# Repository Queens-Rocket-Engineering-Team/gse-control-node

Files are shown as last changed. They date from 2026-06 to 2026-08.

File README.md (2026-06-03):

# GSE Control Node

The GSE control node is the control PCB for GSE systems to integrate with launch control. This includes actuator control, fan control, and a load cell reading. This control node is used for control of the GSE equipment on the launch tower.

## System Architecture

Control nodes use an ESP32S3-WROOM-1U microcontroller for systems control. This ESP32S3 communicates with an external control
server to for remote control and data streaming over 2.4GHz WiFi. All commands are sent from the external server, as
control nodes does not autonomously control any systems.

A communications diagram for the GSE control node can be seen below.

```mermaid
---
title: Communications Flow
---
flowchart LR

    ADC(ADS112C04<br>ADCs) <==I2C==> ESP(ESP32 MCU)

    subgraph Controls
        AV(Actuators)
    end

    subgraph Sensors
        LC(Load Cell)
    end

    LC --> ADC

    ESP --> AV

    ESP <-. WiFI .-> WIFI(External Server)
```

## Power Architecture

The GSE control node operates from a 24VDC power supply. The 24V rail is first stepped down to 5.17V with a switching converter and then dropped to 5V and 3.3V with LDOs. The 5V rail supplies analog systems, and the 3.3V rail supplies digital systems. Using LDOs on the switching output allows for low-noise power for analog measurements. There is also a switching converter to step the 24V rail down to 12V, to power fans.

```mermaid
---
title: Power Distribution
---
flowchart LR

    subgraph Actuators
        AV(Actuators)
    end
    24VIN --> AV

    subgraph Voltage Regulation
        BUCK_12([12V Buck])
        BUCK_5.17([5.17V Buck])
        BUCK_5.17 --> 5V([5V LDO])
        BUCK_5.17 --> 3V3([3.3V LDO])
    end

    24VIN --> BUCK_12
    24VIN --> BUCK_5.17

    subgraph Fans
        FANS(Fans)
    end

    subgraph Sensors
        LC(Load Cell)
    end

    BUCK_12 ---> FANS
    5V --> ADC(ADS112C04<br>ADCs)
    3V3 --> ESP(ESP32 MCU)
    3V3 --> ADC
    5V --> LC
```

## Required Software

This project was created using KiCad v10.0. If manufacturing with JLCPCB, install the Fabrication Toolkit KiCad plugin for JLCPCB.

## Recommended Manufacturing Options

If ordering from JLCPCB, use the JLC04161H-3313 stackup option. For JLC PCBA, the standard PCBA option is required due
to the ESP32S3-WROOM-1U being unavailable as a part in the economic PCBA assembly.

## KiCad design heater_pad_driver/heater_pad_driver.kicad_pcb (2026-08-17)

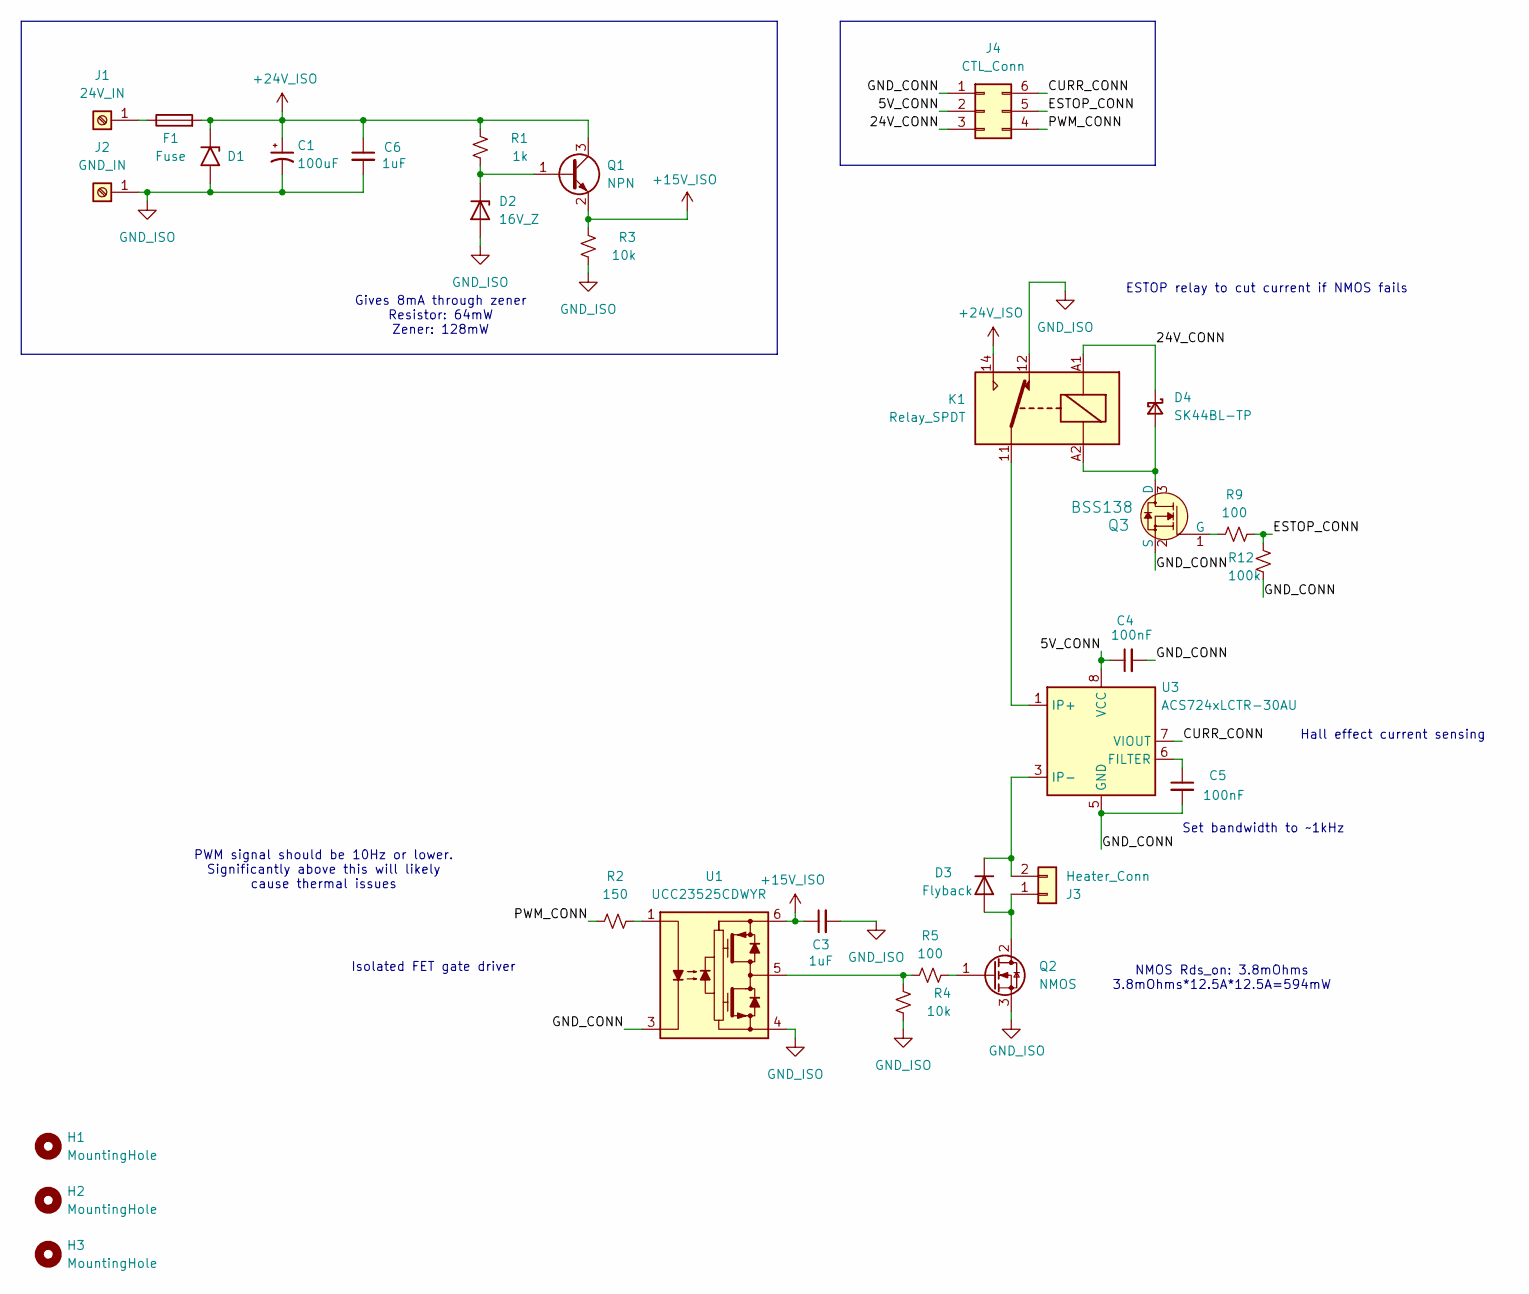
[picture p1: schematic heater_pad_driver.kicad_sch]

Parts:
C1: 100uF; CP_Radial_D8.0mm_P5.00mm; MPN EEU-FR1H101B
C3, C6: 1uF; C_0805_2012Metric_Pad1.18x1.45mm_HandSolder
C4, C5: 100nF; C_0805_2012Metric_Pad1.18x1.45mm_HandSolder
D1: SMCJ26A-13-F; D_SMC
D2: 16V_Z; D_SOD-123; MPN MMSZ5246BT1G
D3: Flyback; TO-220F-2_Vertical; MPN SDURK20Q60
D4: SK44BL-TP; D_SMB_Handsoldering; MPN SK44BL-TP
F1: Fuse; Fuseholder_Blade_Mini_Keystone_3568
H1, H2, H3: MountingHole; MountingHole_3.2mm_M3
J1: 24V_IN; AMT0440007DB0000G; MPN AMT0440007DB0000G
J2: GND_IN; AMT0440007DB0000G; MPN AMT0440007DB0000G
J3: Heater_Conn; AMASS_XT60PW-M_1x02_P7.20mm_Horizontal
J4: CTL_Conn; Molex_Micro-Fit_3.0_43045-0612_2x03_P3.00mm_Vertical
K1: Relay_SPDT; AZ576-1C
Q1: NPN; SOT-23_Handsoldering; MPN MMBTA06LT1G
Q2: NMOS; TO-252-2; MPN DMTH6004SK3Q-13
Q3: BSS138; SOT-23; MPN BSS138
R1: 1k; R_0805_2012Metric_Pad1.20x1.40mm_HandSolder
R2: 150; R_0805_2012Metric_Pad1.20x1.40mm_HandSolder
R3, R4: 10k; R_0805_2012Metric_Pad1.20x1.40mm_HandSolder
R5, R9: 100; R_0805_2012Metric_Pad1.20x1.40mm_HandSolder
R12: 100k; R_0805_2012Metric_Pad1.20x1.40mm_HandSolder
U1: UCC23525CDWYR; SSO-6_6.8x4.6mm_P1.27mm_Clearance8mm
U3: ACS724xLCTR-30AU; SOIC-8_3.9x4.9mm_P1.27mm; MPN ACS724LLCTR-30AU-T

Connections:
+15V_ISO: C3.1, Q1.2 (E), R3.2, U1.6 (VCC)
+24V_ISO: C1.1, C6.1, D1.1 (A1), F1.2, K1.14, Q1.3 (C), R1.2
/5V_CONN: C4.1, J4.2, U3.8 (VCC)
/24V_CONN: D4.1 (K), J4.3, K1.A1
/CURR_CONN: J4.6, U3.7 (VIOUT)
/ESTOP_CONN: J4.5, R9.2, R12.1
/GND_CONN: C4.2, C5.2, J4.1, Q3.2 (S), R12.2, U1.3 (C), U3.5 (GND)
/PWM_CONN: J4.4, R2.2
GND_ISO: C1.2, C3.2, C6.2, D1.2 (A2), D2.2 (A), J2.1 (Pin_1_1), K1.12, Q2.3 (S), R3.1, R4.1, U1.4 (VEE)
unnamed: D2.1 (K), Q1.1 (B), R1.1
unnamed: D3.2 (A), J3.1, Q2.2 (D)
unnamed: D3.1 (K), J3.2, U3.3 (IP-), U3.4 (IP-)
unnamed: D4.2 (A), K1.A2, Q3.3 (D)
unnamed: F1.1, J1.1 (Pin_1_1)
unnamed: K1.11, U3.1 (IP+), U3.2 (IP+)
unnamed: Q2.1 (G), R5.2
unnamed: Q3.1 (G), R9.1
unnamed: R2.1, U1.1 (A)
unnamed: R4.2, R5.1, U1.5 (VO)
unnamed: C5.1, U3.6 (FILTER)

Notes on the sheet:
Gives 8mA through zener Resistor: 64mW Zener: 128mW
Set bandwidth to ~1kHz
ESTOP relay to cut current if NMOS fails
Isolated FET gate driver
Hall effect current sensing
PWM signal should be 10Hz or lower. Significantly above this will likely cause thermal issues
NMOS Rds_on: 3.8mOhms 3.8mOhms*12.5A*12.5A=594mW

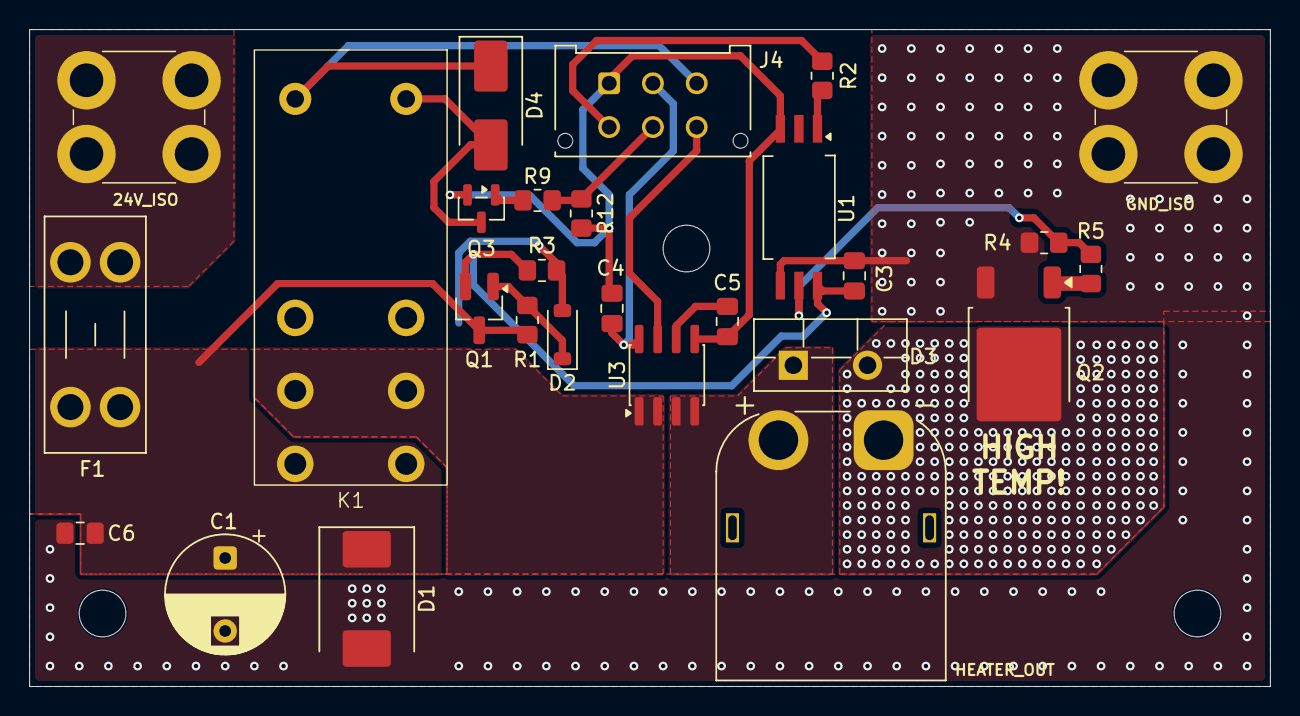
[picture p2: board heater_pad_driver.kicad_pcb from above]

Board: 2 copper layers, 85.0 x 45.0 mm, 30 parts (0 on the bottom side), 20 nets.

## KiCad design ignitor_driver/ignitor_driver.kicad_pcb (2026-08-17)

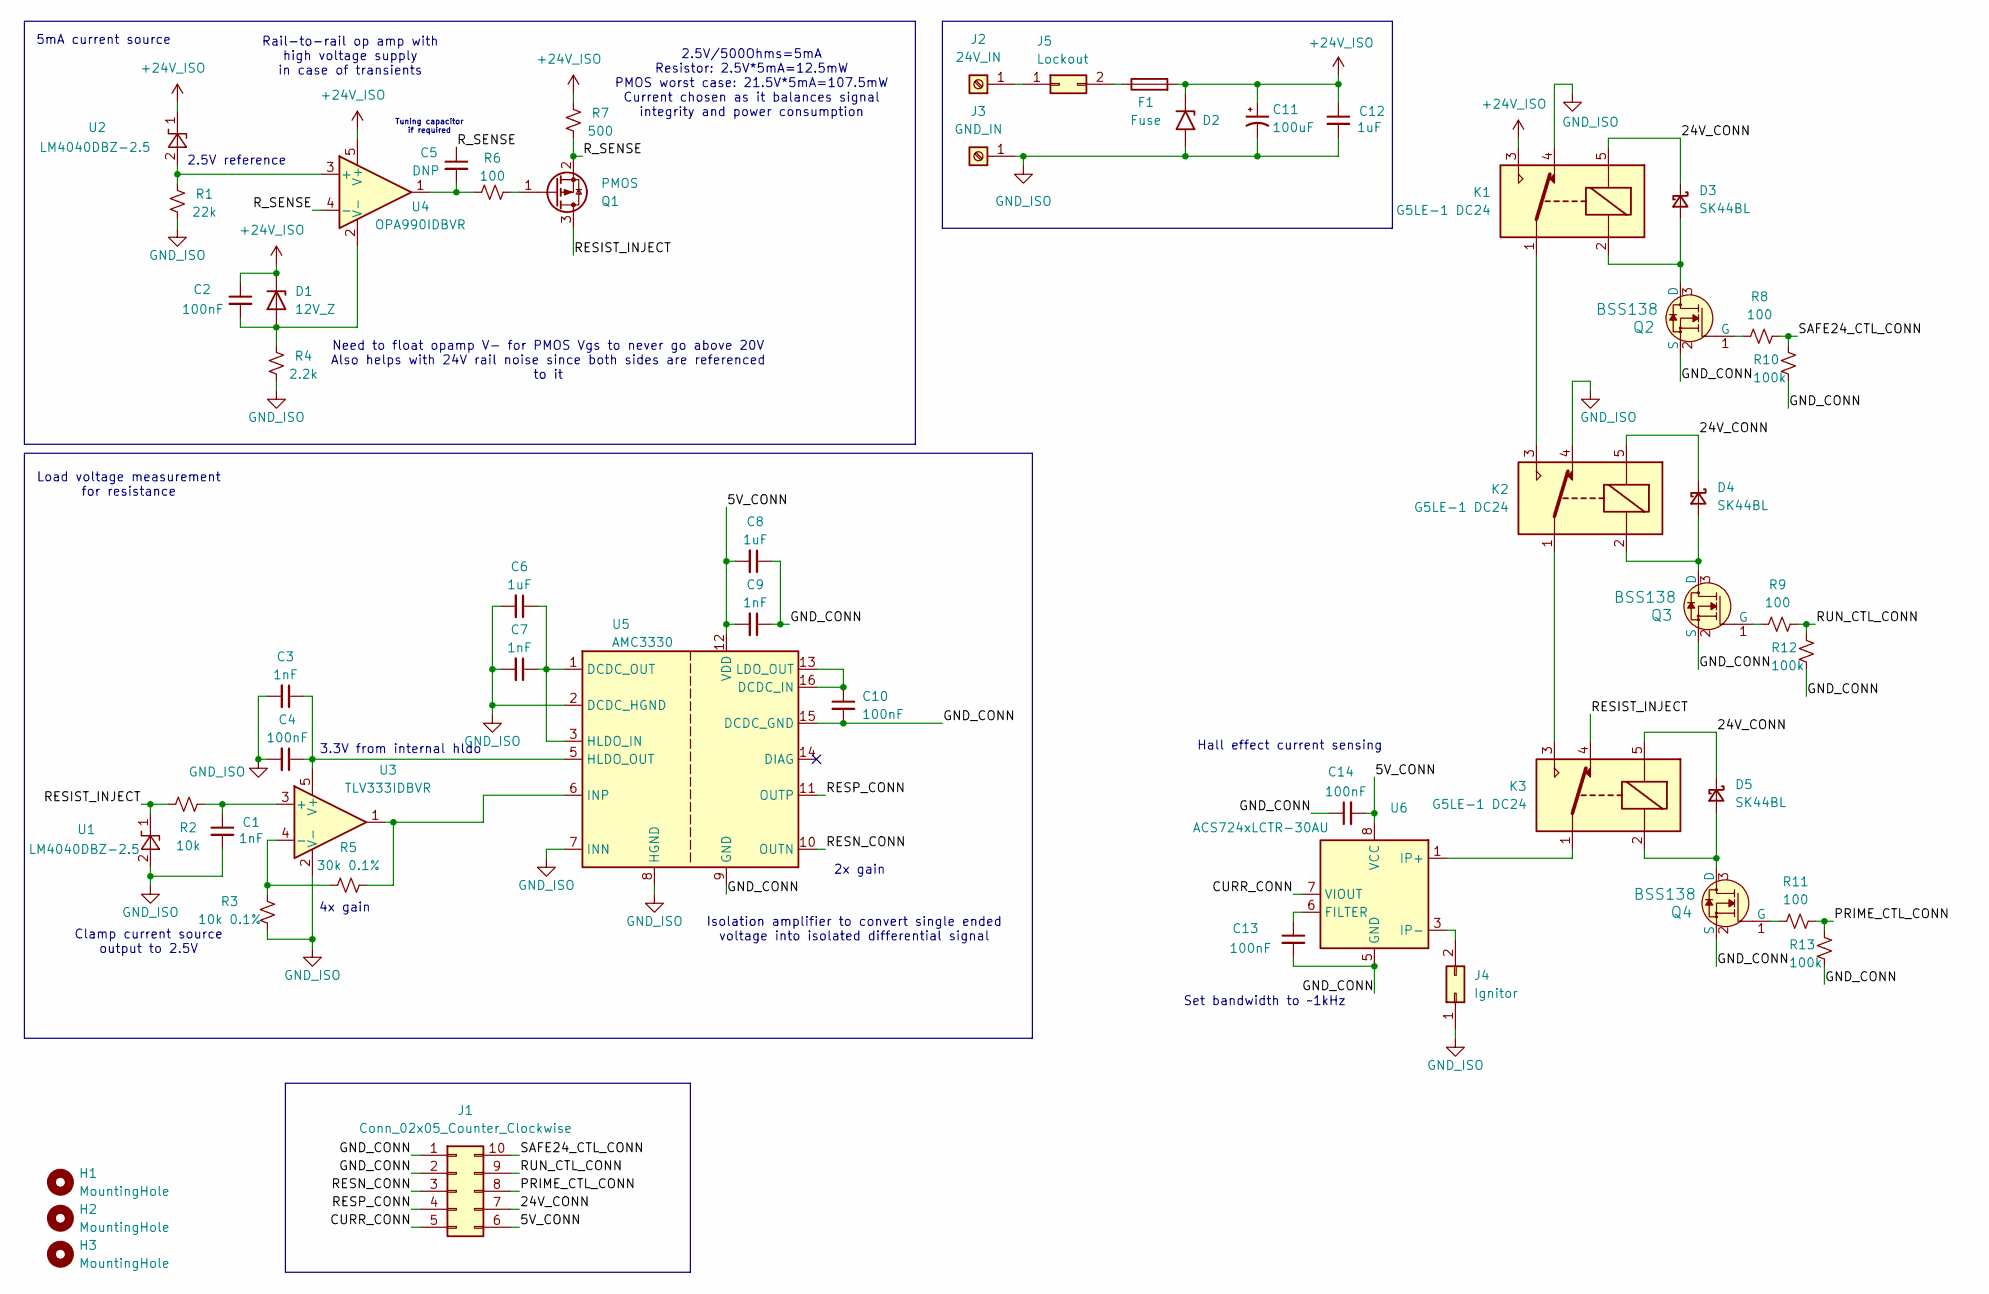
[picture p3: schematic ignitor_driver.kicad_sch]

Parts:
C1, C3, C7, C9: 1nF; C_0805_2012Metric_Pad1.18x1.45mm_HandSolder
C2, C4, C10, C13, C14: 100nF; C_0805_2012Metric_Pad1.18x1.45mm_HandSolder
C5: DNP; C_0805_2012Metric_Pad1.18x1.45mm_HandSolder
C6, C8, C12: 1uF; C_0805_2012Metric_Pad1.18x1.45mm_HandSolder
C11: 100uF; CP_Radial_D8.0mm_P5.00mm; MPN EEU-FR1H101B
D1: 12V_Z; D_SOD-123; MPN BZT52C12-13-F
D2: SMCJ26A-13-F; D_SMC; MPN SMCJ26A
D3, D4, D5: SK44BL; D_SMB_Handsoldering; MPN SK44BL-TP
F1: Fuse; Fuseholder_Blade_Mini_Keystone_3568
H1, H2, H3: MountingHole; MountingHole_3.2mm_M3
J1: Conn_02x05_Counter_Clockwise; Molex_Micro-Fit_3.0_43045-1012_2x05_P3.00mm_Vertical
J2: 24V_IN; AMT0440007DB0000G; MPN AMT0440007DB0000G
J3: GND_IN; AMT0440007DB0000G; MPN AMT0440007DB0000G
J4: Ignitor; Molex_Mini-Fit_Jr_5566-02A_2x01_P4.20mm_Vertical
J5: Lockout; Molex_Mini-Fit_Jr_5566-02A_2x01_P4.20mm_Vertical
K1, K2, K3: G5LE-1 DC24; Relay_SPDT_Omron-G5LE-1
Q1: PMOS; SOT-23; MPN BSS83PH6327XTSA1
Q2, Q3, Q4: BSS138; SOT-23; MPN BSS138
R1: 22k; R_0805_2012Metric_Pad1.20x1.40mm_HandSolder; MPN 0402WGF1000TCE
R2: 10k; R_0805_2012Metric_Pad1.20x1.40mm_HandSolder; MPN 0402WGF1000TCE
R3: 10k 0.1%; R_0805_2012Metric_Pad1.20x1.40mm_HandSolder; MPN 0402WGF1000TCE
R4: 2.2k; R_0805_2012Metric_Pad1.20x1.40mm_HandSolder; MPN 0402WGF1000TCE
R5: 30k 0.1%; R_0805_2012Metric_Pad1.20x1.40mm_HandSolder; MPN 0402WGF1000TCE
R6, R8, R9, R11: 100; R_0805_2012Metric_Pad1.20x1.40mm_HandSolder; MPN 0402WGF1000TCE
R7: 500; R_0603_1608Metric_Pad0.98x0.95mm_HandSolder; MPN 0402WGF1000TCE
R10, R12, R13: 100k; R_0805_2012Metric_Pad1.20x1.40mm_HandSolder; MPN 0402WGJ0103TCE
U1, U2: LM4040DBZ-2.5; SOT-23; MPN LM4040C25FTA
U3: TLV333IDBVR; SOT-23-5_HandSoldering
U4: OPA990IDBVR; SOT-23-5_HandSoldering
U5: AMC3330; SOIC-16W_7.5x10.3mm_P1.27mm; MPN AMC3330DWER
U6: ACS724xLCTR-30AU; SOIC-8_3.9x4.9mm_P1.27mm; MPN ACS724LLCTR-30AU-T

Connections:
+24V_ISO: C2.1, C11.1, C12.1, D1.1 (K), D2.1 (A1), F1.2, K1.3, R7.1, U2.1 (K), U4.5 (V+)
/5V_CONN: C8.2, C9.2, C14.2, J1.6, U5.12 (VDD), U6.8 (VCC)
/24V_CONN: D3.1 (K), D4.1 (K), D5.1 (K), J1.7, K1.5, K2.5, K3.5
/CURR_CONN: J1.5, U6.7 (VIOUT)
/GND_CONN: C8.1, C9.1, C10.2, C13.2, C14.1, J1.1, J1.2, Q2.2 (S), Q3.2 (S), Q4.2 (S), R10.2, R12.2, R13.2, U5.9 (GND), U5.15 (DCDC_GND), U6.5 (GND)
/PRIME_CTL_CONN: J1.8, R11.2, R13.1
/RESIST_INJECT: K3.4, Q1.3 (D), R2.1, U1.1 (K)
/RESN_CONN: J1.3, U5.10 (OUTN)
/RESP_CONN: J1.4, U5.11 (OUTP)
/RUN_CTL_CONN: J1.9, R9.2, R12.1
/R_SENSE: C5.1, Q1.2 (S), R7.2, U4.4 (-)
/SAFE24_CTL_CONN: J1.10, R8.2, R10.1
GND_ISO: C1.2, C3.2, C4.2, C6.2, C7.2, C11.2, C12.2, D2.2 (A2), J3.1 (Pin_1_1), J4.1, K1.4, K2.4, R1.2, R3.1, R4.2, U1.2 (A), U3.2 (V-), U5.2 (DCDC_HGND), U5.7 (INN), U5.8 (HGND)
unnamed: C5.2, R6.1, U4.1
unnamed: C2.2, D1.2 (A), R4.1, U4.2 (V-)
unnamed: D3.2 (A), K1.2, Q2.3 (D)
unnamed: D4.2 (A), K2.2, Q3.3 (D)
unnamed: D5.2 (A), K3.2, Q4.3 (D)
unnamed: J2.1 (Pin_1_1), J5.1
unnamed: J4.2, U6.3 (IP-), U6.4 (IP-)
unnamed: F1.1, J5.2
unnamed: K1.1, K2.3
unnamed: K2.1, K3.3
unnamed: K3.1, U6.1 (IP+), U6.2 (IP+)
unnamed: Q1.1 (G), R6.2
unnamed: Q2.1 (G), R8.1
unnamed: Q3.1 (G), R9.1
unnamed: Q4.1 (G), R11.1
unnamed: R1.1, U2.2 (A), U4.3 (+)
unnamed: C1.1, R2.2, U3.3 (+)
unnamed: R3.2, R5.1, U3.4 (-)
unnamed: C3.1, C4.1, U3.5 (V+), U5.5 (HLDO_OUT)
unnamed: C10.1, U5.13 (LDO_OUT), U5.16 (DCDC_IN)
unnamed: C6.1, C7.1, U5.1 (DCDC_OUT), U5.3 (HLDO_IN)
unnamed: R5.2, U3.1, U5.6 (INP)
unnamed: C13.1, U6.6 (FILTER)

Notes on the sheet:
5mA current source
Hall effect current sensing
4x gain
Clamp current source output to 2.5V
Need to float opamp V- for PMOS Vgs to never go above 20V Also helps with 24V rail noise since both sides are referenced to it
Load voltage measurement for resistance
2.5V/500Ohms=5mA Resistor: 2.5V*5mA=12.5mW PMOS worst case: 21.5V*5mA=107.5mW Current chosen as it balances signal integrity and power consumption
Rail-to-rail op amp with high voltage supply in case of transients
2x gain
Isolation amplifier to convert single ended voltage into isolated differential signal
Tuning capacitor if required
Set bandwidth to ~1kHz
2.5V reference
3.3V from internal hldo

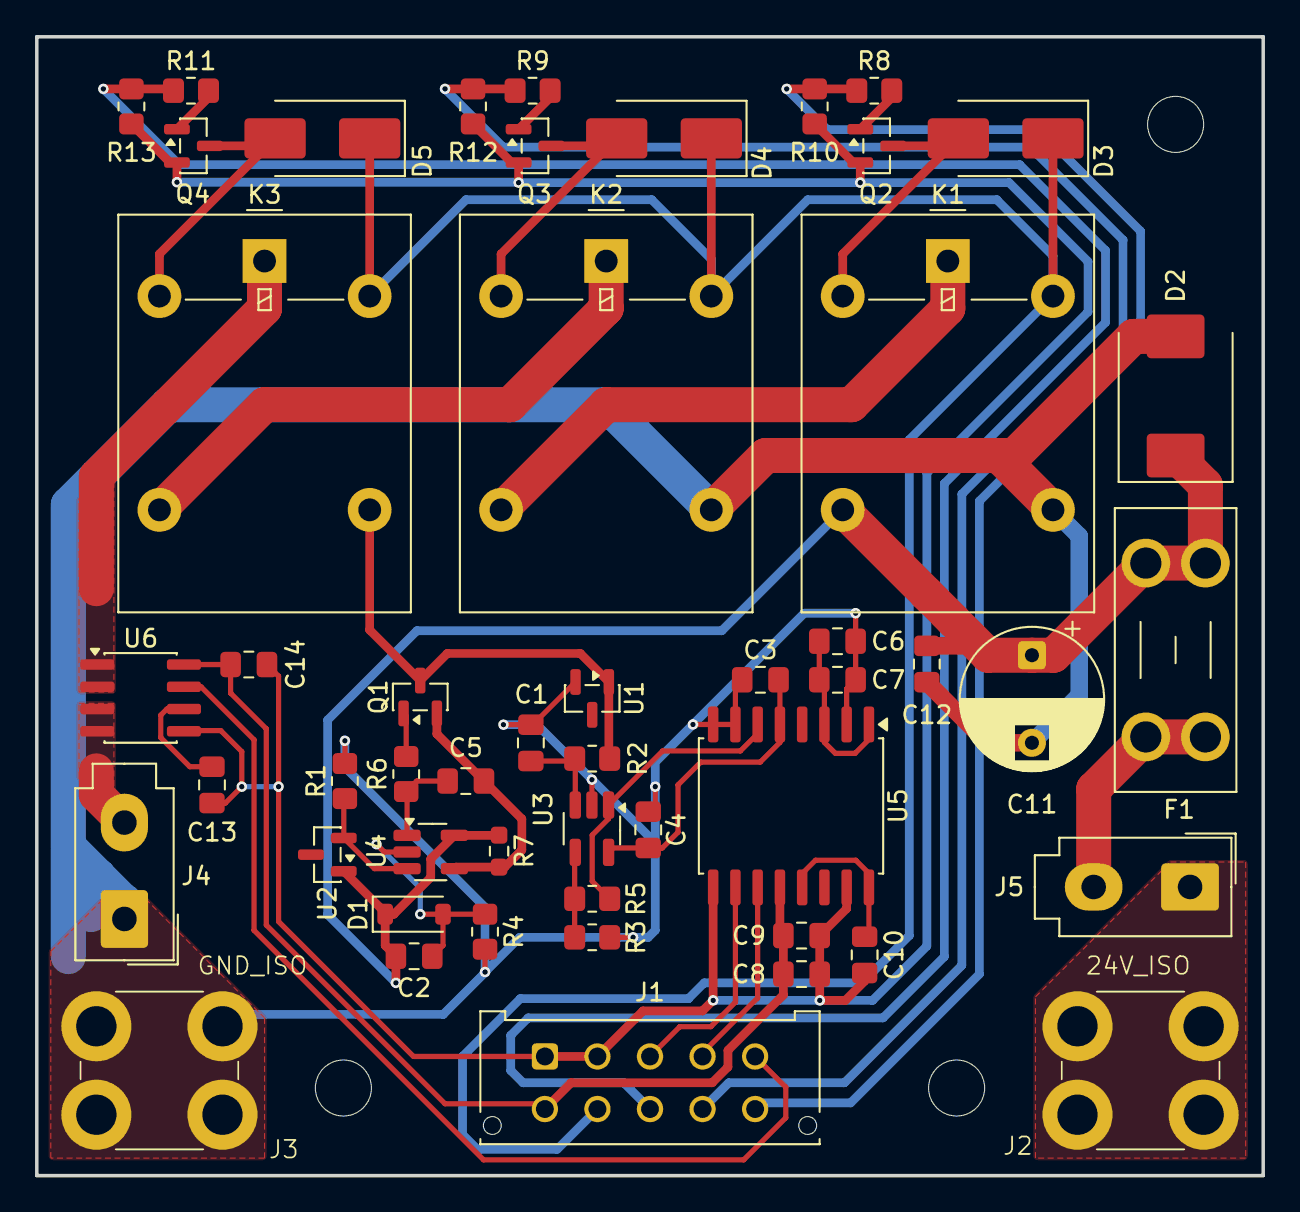
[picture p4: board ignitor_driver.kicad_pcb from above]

Board: 2 copper layers, 70.0 x 65.0 mm, 54 parts (0 on the bottom side), 36 nets.

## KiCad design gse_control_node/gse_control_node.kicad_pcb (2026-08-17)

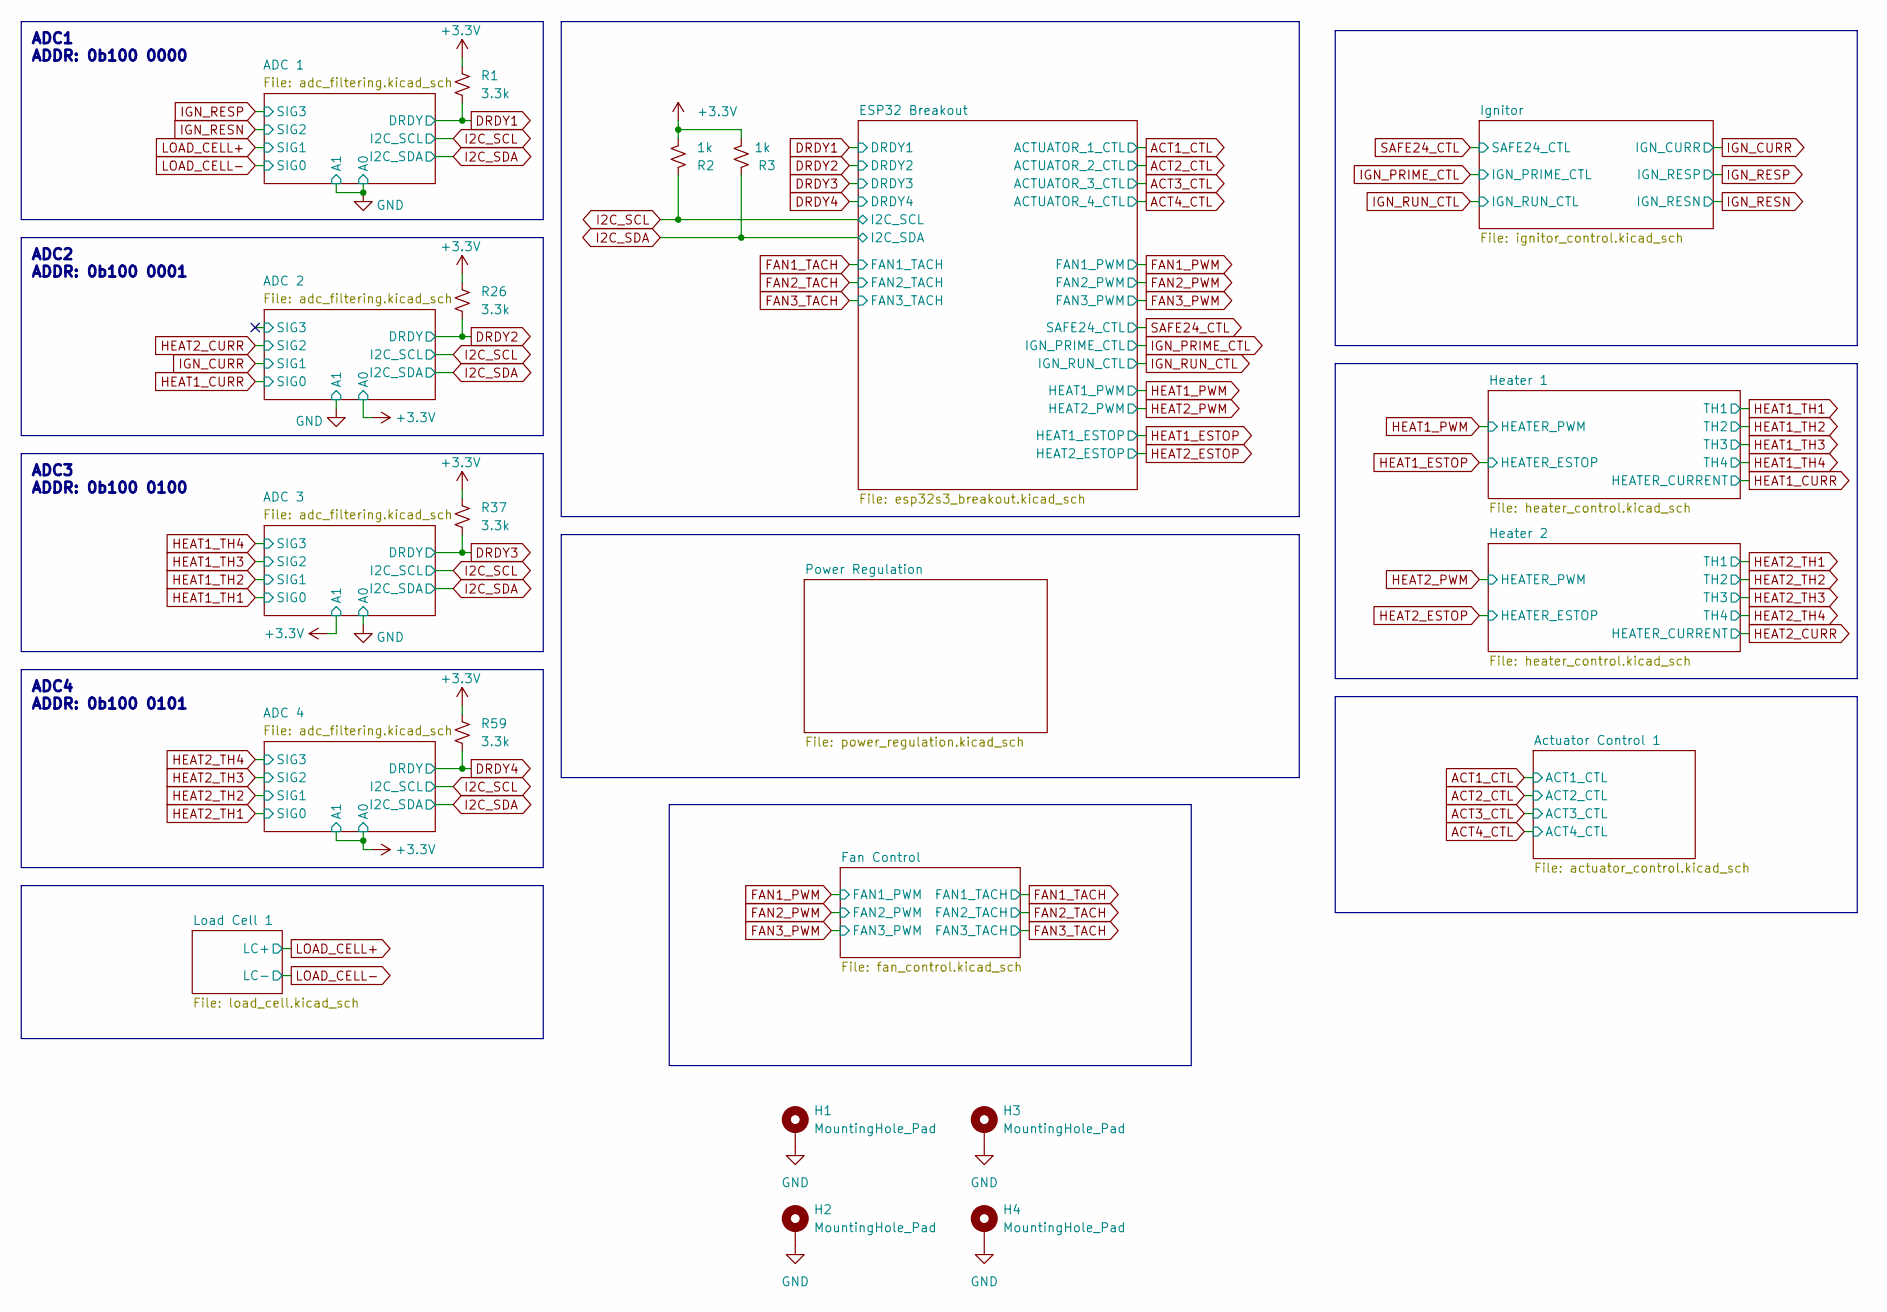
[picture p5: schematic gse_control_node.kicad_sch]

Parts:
H1, H2, H3, H4: MountingHole_Pad; MountingHole_3.2mm_M3_ISO7380_Pad; LCSC N/A
R1, R26, R37, R59: 3.3k; R_0603_1608Metric; LCSC C22978
R2, R3: 1k; R_0603_1608Metric; LCSC C21190

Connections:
+3.3V: R1.1, R2.2, R3.2, R26.1, R37.1, R59.1; also elsewhere on the board
DRDY1: R1.2; also elsewhere on the board
DRDY2: R26.2; also elsewhere on the board
DRDY3: R37.2; also elsewhere on the board
DRDY4: R59.2; also elsewhere on the board
GND: H1.1 (1_1), H2.1 (1_1), H3.1 (1_1), H4.1 (1_1); also elsewhere on the board
I2C_SCL: R2.1; also elsewhere on the board
I2C_SDA: R3.1; also elsewhere on the board

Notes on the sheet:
ADC2 ADDR: 0b100 0001
ADC4 ADDR: 0b100 0101
ADC1 ADDR: 0b100 0000
ADC3 ADDR: 0b100 0100

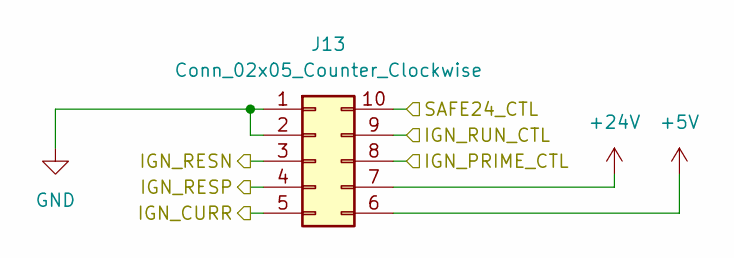
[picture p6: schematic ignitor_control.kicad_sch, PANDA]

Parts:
J13: Conn_02x05_Counter_Clockwise; Molex_Micro-Fit_3.0_43045-1012_2x05_P3.00mm_Vertical

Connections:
+5V: J13.6; also elsewhere on the board
+24V: J13.7; also elsewhere on the board
GND: J13.1, J13.2; also elsewhere on the board
IGN_CURR: J13.5; also elsewhere on the board
IGN_PRIME_CTL: J13.8; also elsewhere on the board
IGN_RESN: J13.3; also elsewhere on the board
IGN_RESP: J13.4; also elsewhere on the board
IGN_RUN_CTL: J13.9; also elsewhere on the board
SAFE24_CTL: J13.10; also elsewhere on the board

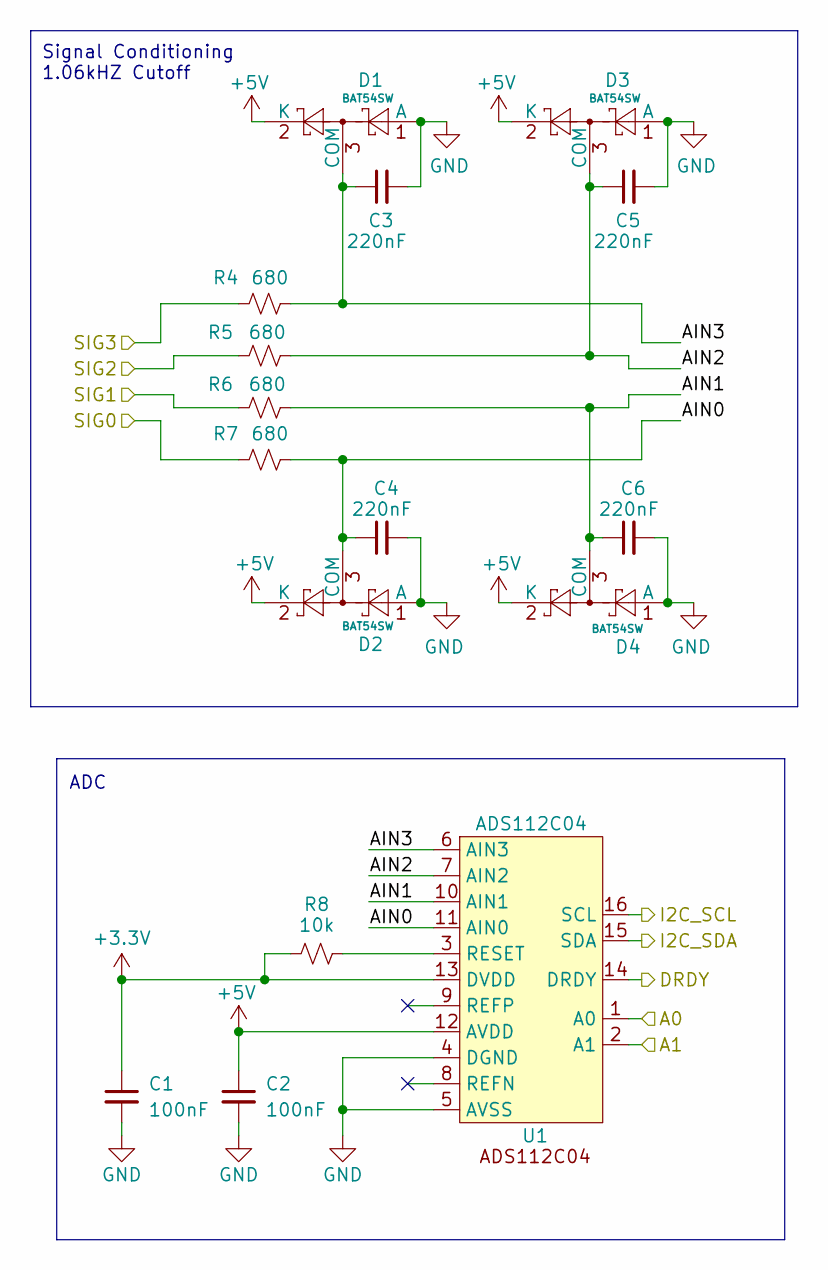
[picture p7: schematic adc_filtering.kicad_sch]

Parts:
C1, C2: 100nF; C_0402_1005Metric; LCSC C307331
C3, C4, C5, C6: 220nF; C_0402_1005Metric; LCSC C16772
D1, D2, D3, D4: BAT54SW; SOT-323_SC-70; LCSC C83575
R4, R5, R6, R7: 680; R_0603_1608Metric; LCSC C23228
R8: 10k; R_0603_1608Metric; LCSC C25804
U1: ADS112C04; TSSOP-16_4.4x5mm_P0.65mm; LCSC C701615

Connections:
+3.3V: C1.1, R8.1, U1.13 (DVDD); also elsewhere on the board
+5V: C2.1, D1.2 (K), D2.2 (K), D3.2 (K), D4.2 (K), U1.12 (AVDD); also elsewhere on the board
/ADC 1/AIN0: C4.1, D2.3 (COM), R7.2, U1.11 (AIN0)
/ADC 1/AIN1: C6.1, D4.3 (COM), R6.2, U1.10 (AIN1)
/ADC 1/AIN2: C5.1, D3.3 (COM), R5.2, U1.7 (AIN2)
/ADC 1/AIN3: C3.1, D1.3 (COM), R4.2, U1.6 (AIN3)
DRDY1: U1.14 (DRDY); also elsewhere on the board
GND: C1.2, C2.2, C3.2, C4.2, C5.2, C6.2, D1.1 (A), D2.1 (A), D3.1 (A), D4.1 (A), U1.1 (A0), U1.2 (A1), U1.4 (DGND), U1.5 (AVSS); also elsewhere on the board
I2C_SCL: U1.16 (SCL); also elsewhere on the board
I2C_SDA: U1.15 (SDA); also elsewhere on the board
IGN_RESN: R5.1; also elsewhere on the board
IGN_RESP: R4.1; also elsewhere on the board
LOAD_CELL+: R6.1; also elsewhere on the board
LOAD_CELL-: R7.1; also elsewhere on the board
unnamed: R8.2, U1.3 (RESET)

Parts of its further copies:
C37, C38, C43, C44, C49, C50: 100nF; C_0402_1005Metric; LCSC C307331
C39, C40, C41, C42, C45, C46, C47, C48, C51, C52, C53, C54: 220nF; C_0402_1005Metric; LCSC C16772
D12, D13, D14, D16, D17, D18, D20, D21, D22, D24, D25, D26: BAT54SW; SOT-323_SC-70; LCSC C83575
R27, R28, R29, R30, R49, R50, R51, R55, R60, R61, R62, R63: 680; R_0603_1608Metric; LCSC C23228
R31, R56, R64: 10k; R_0603_1608Metric; LCSC C25804
U8, U9, U10: ADS112C04; TSSOP-16_4.4x5mm_P0.65mm; LCSC C701615

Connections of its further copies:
+3.3V: C37.1, C43.1, C49.1, R31.1, R56.1, R64.1, U8.1 (A0), U8.13 (DVDD), U9.2 (A1), U9.13 (DVDD), U10.1 (A0), U10.2 (A1), U10.13 (DVDD); also elsewhere on the board
+5V: C38.1, C44.1, C50.1, D12.2 (K), D13.2 (K), D14.2 (K), D16.2 (K), D17.2 (K), D18.2 (K), D20.2 (K), D21.2 (K), D22.2 (K), D24.2 (K), D25.2 (K), D26.2 (K), U8.12 (AVDD), U9.12 (AVDD), U10.12 (AVDD); also elsewhere on the board
/ADC 2/AIN0: C40.1, D13.3 (COM), R30.2, U8.11 (AIN0)
/ADC 2/AIN1: C42.1, D16.3 (COM), R29.2, U8.10 (AIN1)
/ADC 2/AIN2: C41.1, D14.3 (COM), R28.2, U8.7 (AIN2)
/ADC 2/AIN3: C39.1, D12.3 (COM), R27.2, U8.6 (AIN3)
/ADC 2/SIG3: R27.1
/ADC 3/AIN0: C46.1, D18.3 (COM), R55.2, U9.11 (AIN0)
/ADC 3/AIN1: C48.1, D21.3 (COM), R51.2, U9.10 (AIN1)
/ADC 3/AIN2: C47.1, D20.3 (COM), R50.2, U9.7 (AIN2)
/ADC 3/AIN3: C45.1, D17.3 (COM), R49.2, U9.6 (AIN3)
/ADC 4/AIN0: C52.1, D24.3 (COM), R63.2, U10.11 (AIN0)
/ADC 4/AIN1: C54.1, D26.3 (COM), R62.2, U10.10 (AIN1)
/ADC 4/AIN2: C53.1, D25.3 (COM), R61.2, U10.7 (AIN2)
/ADC 4/AIN3: C51.1, D22.3 (COM), R60.2, U10.6 (AIN3)
DRDY2: U8.14 (DRDY); also elsewhere on the board
DRDY3: U9.14 (DRDY); also elsewhere on the board
DRDY4: U10.14 (DRDY); also elsewhere on the board
GND: C37.2, C38.2, C39.2, C40.2, C41.2, C42.2, C43.2, C44.2, C45.2, C46.2, C47.2, C48.2, C49.2, C50.2, C51.2, C52.2, C53.2, C54.2, D12.1 (A), D13.1 (A), D14.1 (A), D16.1 (A), D17.1 (A), D18.1 (A), D20.1 (A), D21.1 (A), D22.1 (A), D24.1 (A), D25.1 (A), D26.1 (A), U8.2 (A1), U8.4 (DGND), U8.5 (AVSS), U9.1 (A0), U9.4 (DGND), U9.5 (AVSS), U10.4 (DGND), U10.5 (AVSS); also elsewhere on the board
HEAT1_CURR: R30.1; also elsewhere on the board
HEAT1_TH1: R55.1; also elsewhere on the board
HEAT1_TH2: R51.1; also elsewhere on the board
HEAT1_TH3: R50.1; also elsewhere on the board
HEAT1_TH4: R49.1; also elsewhere on the board
HEAT2_CURR: R28.1; also elsewhere on the board
HEAT2_TH1: R63.1; also elsewhere on the board
HEAT2_TH2: R62.1; also elsewhere on the board
HEAT2_TH3: R61.1; also elsewhere on the board
HEAT2_TH4: R60.1; also elsewhere on the board
I2C_SCL: U8.16 (SCL), U9.16 (SCL), U10.16 (SCL); also elsewhere on the board
I2C_SDA: U8.15 (SDA), U9.15 (SDA), U10.15 (SDA); also elsewhere on the board
IGN_CURR: R29.1; also elsewhere on the board
unnamed: R31.2, U8.3 (RESET)
unnamed: R56.2, U9.3 (RESET)
unnamed: R64.2, U10.3 (RESET)

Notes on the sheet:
ADC
Signal Conditioning 1.06kHZ Cutoff

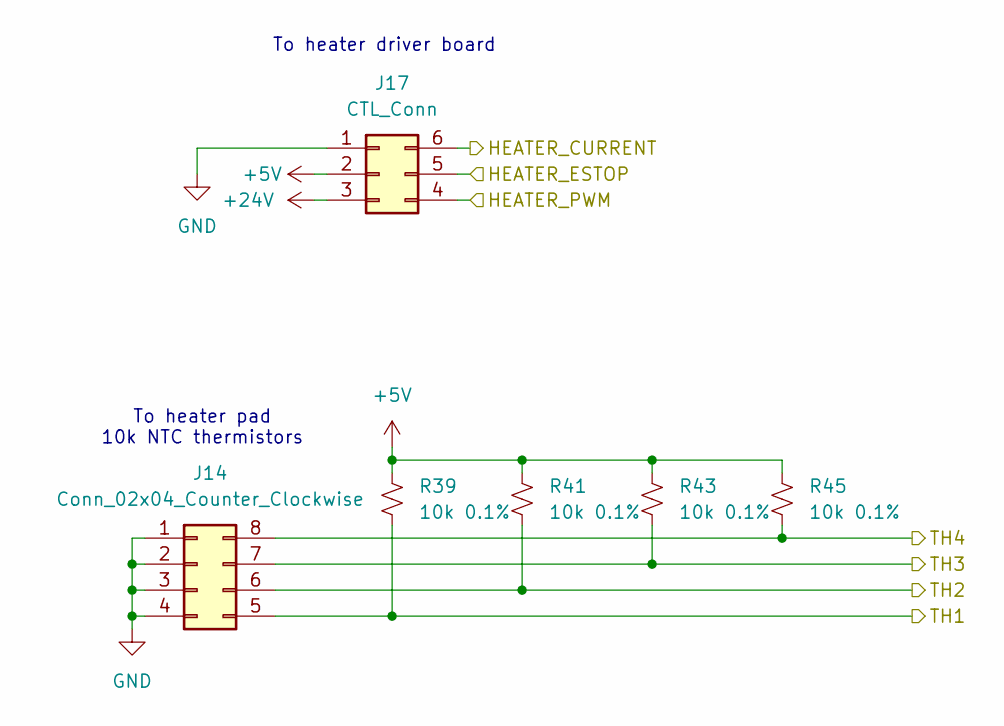
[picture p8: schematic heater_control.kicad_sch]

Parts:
J14: Conn_02x04_Counter_Clockwise; Molex_Micro-Fit_3.0_43045-0812_2x04_P3.00mm_Vertical
J17: CTL_Conn; Molex_Micro-Fit_3.0_43045-0612_2x03_P3.00mm_Vertical
R39, R41, R43, R45: 10k 0.1%; R_0603_1608Metric

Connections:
+5V: J17.2, R39.1, R41.1, R43.1, R45.1; also elsewhere on the board
+24V: J17.3; also elsewhere on the board
GND: J14.1, J14.2, J14.3, J14.4, J17.1; also elsewhere on the board
HEAT2_CURR: J17.6; also elsewhere on the board
HEAT2_ESTOP: J17.5; also elsewhere on the board
HEAT2_PWM: J17.4; also elsewhere on the board
HEAT2_TH1: J14.5, R39.2; also elsewhere on the board
HEAT2_TH2: J14.6, R41.2; also elsewhere on the board
HEAT2_TH3: J14.7, R43.2; also elsewhere on the board
HEAT2_TH4: J14.8, R45.2; also elsewhere on the board

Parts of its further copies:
J12: Conn_02x04_Counter_Clockwise; Molex_Micro-Fit_3.0_43045-0812_2x04_P3.00mm_Vertical
J16: CTL_Conn; Molex_Micro-Fit_3.0_43045-0612_2x03_P3.00mm_Vertical
R38, R40, R42, R44: 10k 0.1%; R_0603_1608Metric

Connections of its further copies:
+5V: J16.2, R38.1, R40.1, R42.1, R44.1; also elsewhere on the board
+24V: J16.3; also elsewhere on the board
GND: J12.1, J12.2, J12.3, J12.4, J16.1; also elsewhere on the board
HEAT1_CURR: J16.6; also elsewhere on the board
HEAT1_ESTOP: J16.5; also elsewhere on the board
HEAT1_PWM: J16.4; also elsewhere on the board
HEAT1_TH1: J12.5, R38.2; also elsewhere on the board
HEAT1_TH2: J12.6, R40.2; also elsewhere on the board
HEAT1_TH3: J12.7, R42.2; also elsewhere on the board
HEAT1_TH4: J12.8, R44.2; also elsewhere on the board

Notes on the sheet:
To heater driver board
To heater pad 10k NTC thermistors

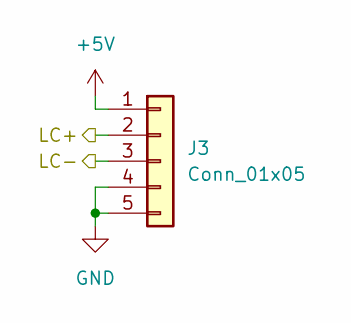
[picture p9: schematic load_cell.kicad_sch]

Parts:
J3: Conn_01x05; Molex_Micro-Fit_3.0_43650-0515_1x05_P3.00mm_Vertical; LCSC N/A

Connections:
+5V: J3.1; also elsewhere on the board
GND: J3.4, J3.5; also elsewhere on the board
LOAD_CELL+: J3.2; also elsewhere on the board
LOAD_CELL-: J3.3; also elsewhere on the board

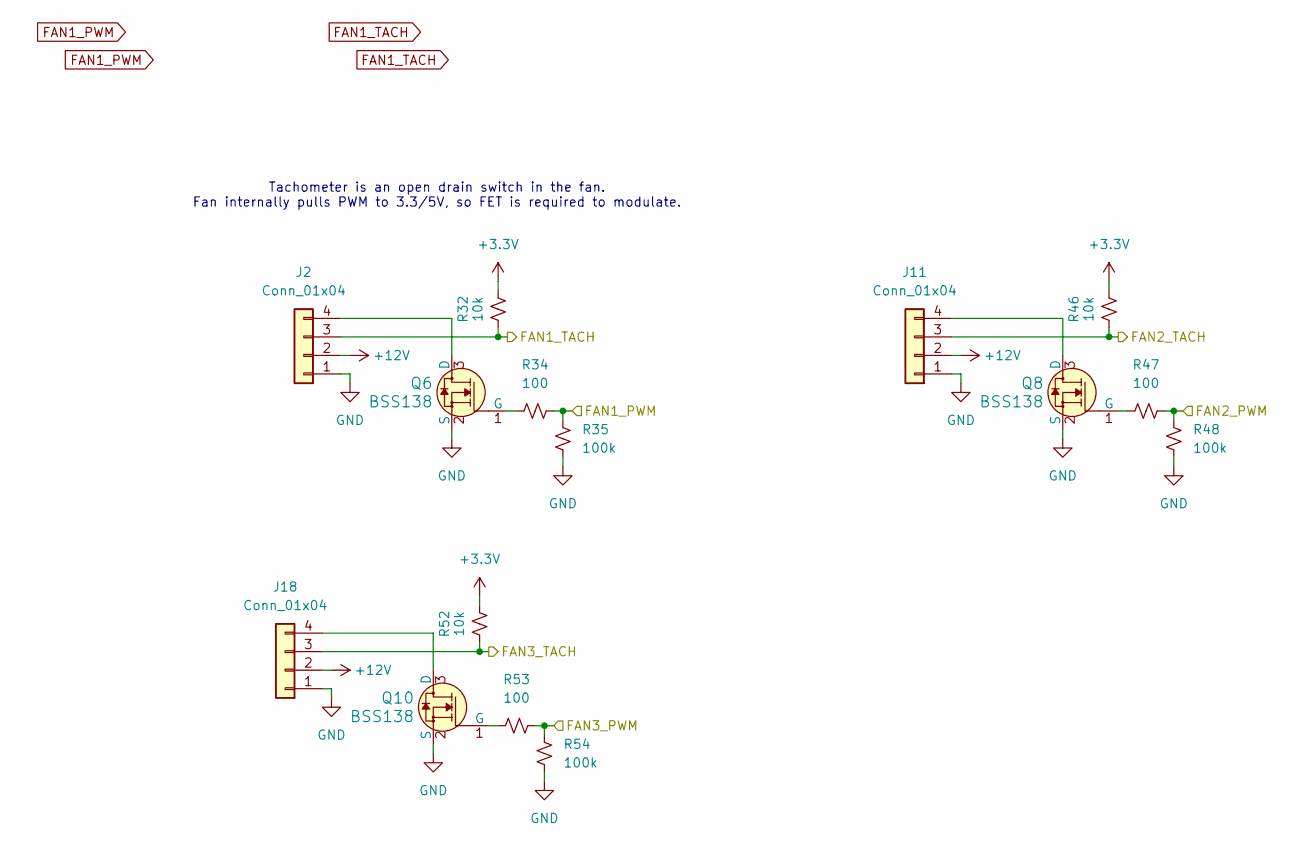
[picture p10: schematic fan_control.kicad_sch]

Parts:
J2, J11, J18: Conn_01x04; Molex_KK-254_AE-6410-04A_1x04_P2.54mm_Vertical; LCSC N/A
Q6, Q8, Q10: BSS138; SOT-23-3; LCSC C82045
R32, R46, R52: 10k; R_0603_1608Metric; LCSC C25804
R34, R47, R53: 100; R_0603_1608Metric
R35, R48, R54: 100k; R_0603_1608Metric; LCSC C122538

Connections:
+3.3V: R32.2, R46.2, R52.2; also elsewhere on the board
+12V: J2.2, J11.2, J18.2; also elsewhere on the board
FAN1_PWM: R34.2, R35.1; also elsewhere on the board
FAN1_TACH: J2.3, R32.1; also elsewhere on the board
FAN2_PWM: R47.2, R48.1; also elsewhere on the board
FAN2_TACH: J11.3, R46.1; also elsewhere on the board
FAN3_PWM: R53.2, R54.1; also elsewhere on the board
FAN3_TACH: J18.3, R52.1; also elsewhere on the board
GND: J2.1, J11.1, J18.1, Q6.2 (S), Q8.2 (S), Q10.2 (S), R35.2, R48.2, R54.2; also elsewhere on the board
unnamed: J2.4, Q6.3 (D)
unnamed: J11.4, Q8.3 (D)
unnamed: J18.4, Q10.3 (D)
unnamed: Q6.1 (G), R34.1
unnamed: Q8.1 (G), R47.1
unnamed: Q10.1 (G), R53.1

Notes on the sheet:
Tachometer is an open drain switch in the fan. Fan internally pulls PWM to 3.3/5V, so FET is required to modulate.

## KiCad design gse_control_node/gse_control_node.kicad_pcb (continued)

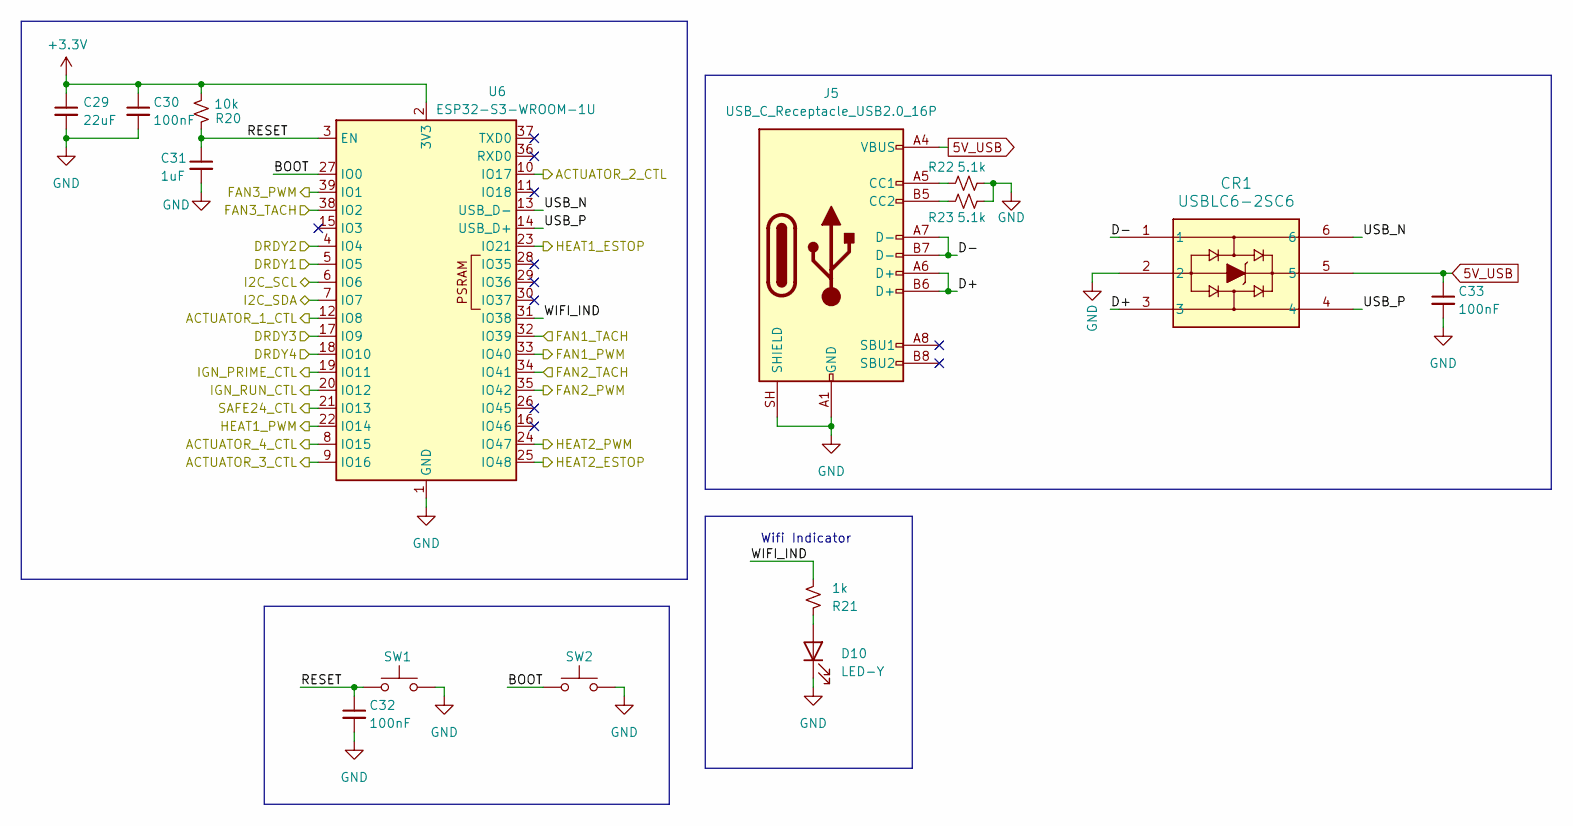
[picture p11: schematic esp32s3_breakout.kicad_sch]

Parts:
C29: 22uF; C_0805_2012Metric; LCSC C45783
C30, C32, C33: 100nF; C_0402_1005Metric; LCSC C307331
C31: 1uF; C_0603_1608Metric; LCSC C15849
CR1: USBLC6-2SC6; SOT-23-6; LCSC C7519
D10: LED-Y; LED_0805_2012Metric; LCSC C2296
J5: USB_C_Receptacle_USB2.0_16P; USB_C_Receptacle_G-Switch_GT-USB-7051x; LCSC C2843970
R20: 10k; R_0603_1608Metric; LCSC C25804
R21: 1k; R_0603_1608Metric; LCSC C21190
R22, R23: 5.1k; R_0603_1608Metric
SW1, SW2: USAKRO UK-B0227-G4.3-B-250; SW_Tactile_SPST_NO_Straight_CK_PTS636Sx25SMTRLFS; LCSC C556661
U6: ESP32-S3-WROOM-1U; LCSC C2913202

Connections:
5V_USB: C33.1, CR1.5, J5.A4 (VBUS), J5.A9 (VBUS), J5.B4 (VBUS), J5.B9 (VBUS); also elsewhere on the board
+3.3V: C29.1, C30.1, R20.2, U6.2 (3V3); also elsewhere on the board
/ESP32 Breakout/BOOT: SW2.1, U6.27 (IO0)
/ESP32 Breakout/D+: CR1.3, J5.A6 (D+), J5.B6 (D+)
/ESP32 Breakout/D-: CR1.1, J5.A7 (D-), J5.B7 (D-)
/ESP32 Breakout/RESET: C31.1, C32.1, R20.1, SW1.1, U6.3 (EN)
/ESP32 Breakout/USB_N: CR1.6, U6.13 (USB_D-)
/ESP32 Breakout/USB_P: CR1.4, U6.14 (USB_D+)
/ESP32 Breakout/WIFI_IND: R21.2, U6.31 (IO38)
ACT1_CTL: U6.12 (IO8); also elsewhere on the board
ACT2_CTL: U6.10 (IO17); also elsewhere on the board
ACT3_CTL: U6.9 (IO16); also elsewhere on the board
ACT4_CTL: U6.8 (IO15); also elsewhere on the board
DRDY1: U6.5 (IO5); also elsewhere on the board
DRDY2: U6.4 (IO4); also elsewhere on the board
DRDY3: U6.17 (IO9); also elsewhere on the board
DRDY4: U6.18 (IO10); also elsewhere on the board
FAN1_PWM: U6.33 (IO40); also elsewhere on the board
FAN1_TACH: U6.32 (IO39); also elsewhere on the board
FAN2_PWM: U6.35 (IO42); also elsewhere on the board
FAN2_TACH: U6.34 (IO41); also elsewhere on the board
FAN3_PWM: U6.39 (IO1); also elsewhere on the board
FAN3_TACH: U6.38 (IO2); also elsewhere on the board
GND: C29.2, C30.2, C31.2, C32.2, C33.2, CR1.2, D10.1 (K), J5.A1 (GND), J5.A12 (GND), J5.B1 (GND), J5.B12 (GND), J5.SH (SHIELD), R22.2, R23.2, SW1.2, SW2.2, U6.1 (GND), U6.40 (GND), U6.41 (GND); also elsewhere on the board
HEAT1_ESTOP: U6.23 (IO21); also elsewhere on the board
HEAT1_PWM: U6.22 (IO14); also elsewhere on the board
HEAT2_ESTOP: U6.25 (IO48); also elsewhere on the board
HEAT2_PWM: U6.24 (IO47); also elsewhere on the board
I2C_SCL: U6.6 (IO6); also elsewhere on the board
I2C_SDA: U6.7 (IO7); also elsewhere on the board
IGN_PRIME_CTL: U6.19 (IO11); also elsewhere on the board
IGN_RUN_CTL: U6.20 (IO12); also elsewhere on the board
unnamed: D10.2 (A), R21.1
unnamed: J5.A5 (CC1), R22.1
unnamed: J5.B5 (CC2), R23.1
SAFE24_CTL: U6.21 (IO13); also elsewhere on the board

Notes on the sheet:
Wifi Indicator

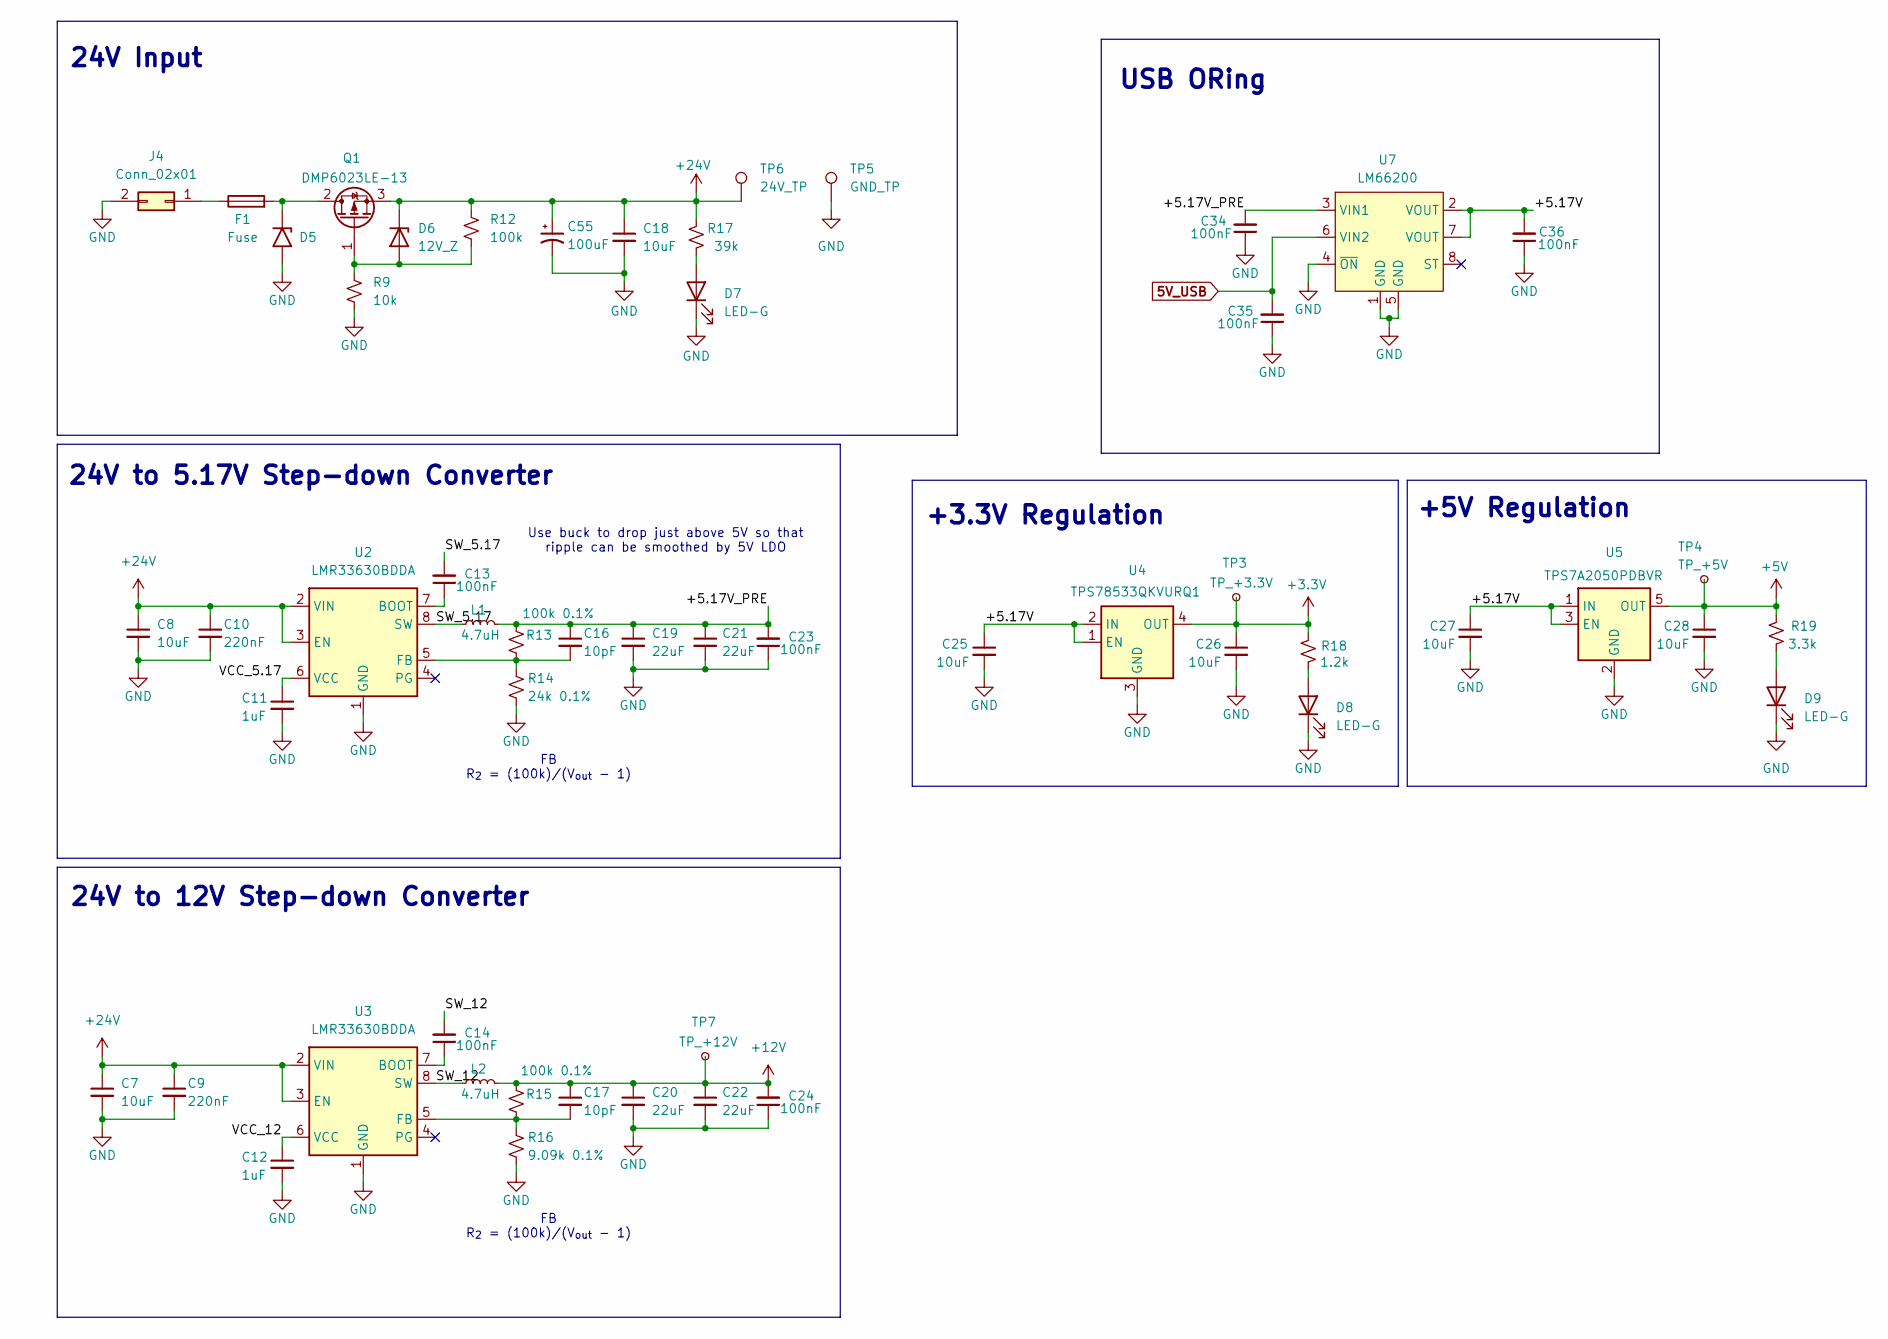
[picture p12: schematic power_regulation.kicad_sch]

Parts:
C7, C8, C18: 10uF; C_1206_3216Metric; LCSC C13585
C9, C10: 220nF; C_0805_2012Metric; LCSC C5378
C11, C12: 1uF; C_0603_1608Metric; LCSC C15849
C13, C14, C23, C24, C34, C35, C36: 100nF; C_0402_1005Metric; LCSC C307331
C16, C17: 10pF; C_0603_1608Metric; LCSC C1634
C19, C20, C21, C22: 22uF; C_0805_2012Metric; LCSC C45783
C25, C26, C27, C28: 10uF; C_0805_2012Metric; LCSC C15850
C55: 100uF; CP_Radial_D8.0mm_P5.00mm; MPN EEU-FR1H101B
D5: SMCJ26A-13-F; D_SMC; LCSC C135156
D6: 12V_Z; D_SOD-123; LCSC C500776
D7, D8, D9: LED-G; LED_0805_2012Metric; LCSC C2297
F1: Fuse; Fuseholder_Blade_Mini_Keystone_3568; LCSC N/A
J4: Conn_02x01; Molex_Mini-Fit_Jr_5566-02A_2x01_P4.20mm_Vertical; LCSC N/A
L1, L2: 4.7uH; L_Bourns_SRP7028A_7.3x6.6mm; LCSC C840529
Q1: DMP6023LE-13; SOT-223-3_TabPin2; LCSC C154901
R9: 10k; R_0603_1608Metric; LCSC C25804
R12: 100k; R_0603_1608Metric; LCSC C122538
R13, R15: 100k 0.1%; R_0603_1608Metric; LCSC C122538
R14: 24k 0.1%; R_0603_1608Metric; LCSC C326729
R16: 9.09k 0.1%; R_0603_1608Metric; LCSC C861611
R17: 39k; R_0603_1608Metric; LCSC C23153
R18: 1.2k; R_0603_1608Metric
R19: 3.3k; R_0603_1608Metric; LCSC C22978
TP3: TP_+3.3V; TestPoint_Pad_D1.0mm; LCSC N/A
TP4: TP_+5V; TestPoint_Pad_D1.0mm; LCSC N/A
TP5: GND_TP; TestPoint_Loop_D2.50mm_Drill1.0mm; LCSC N/A
TP6: 24V_TP; TestPoint_Loop_D2.50mm_Drill1.0mm; LCSC N/A
TP7: TP_+12V; TestPoint_Pad_D1.0mm; LCSC N/A
U2, U3: LMR33630BDDA; Texas_HSOP-8-1EP_3.9x4.9mm_P1.27mm_ThermalVias; LCSC C544370
U4: TPS78533QKVURQ1; TO-252-4; LCSC C3748131
U5: TPS7A2050PDBVR; SOT-23-5; LCSC C2864504
U7: LM66200; SOT-583-8; LCSC C3235556

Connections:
5V_USB: C35.2, U7.6 (VIN2); also elsewhere on the board
+3.3V: C26.1, R18.2, TP3.1 (1_1), U4.4 (OUT); also elsewhere on the board
+5V: C28.1, R19.2, TP4.1 (1_1), U5.5 (OUT); also elsewhere on the board
+12V: C17.1, C20.1, C22.1, C24.2, L2.2, R15.1, TP7.1 (1_1); also elsewhere on the board
+24V: C7.1, C8.1, C9.1, C10.1, C18.1, C55.1, D6.1 (K), Q1.3 (S), R12.1, R17.2, TP6.1 (1_1), U2.2 (VIN), U2.3 (EN), U3.2 (VIN), U3.3 (EN); also elsewhere on the board
/Power Regulation/+5.17V: C25.1, C27.1, C36.2, U4.1 (EN), U4.2 (IN), U5.1 (IN), U5.3 (EN), U7.2 (VOUT), U7.7 (VOUT)
/Power Regulation/+5.17V_PRE: C16.1, C19.1, C21.1, C23.2, C34.2, L1.2, R13.1, U7.3 (VIN1)
/Power Regulation/SW_5.17: C13.2, L1.1, U2.8 (SW)
/Power Regulation/SW_12: C14.2, L2.1, U3.8 (SW)
/Power Regulation/VCC_5.17: C11.1, U2.6 (VCC)
/Power Regulation/VCC_12: C12.1, U3.6 (VCC)
GND: C7.2, C8.2, C9.2, C10.2, C11.2, C12.2, C18.2, C19.2, C20.2, C21.2, C22.2, C23.1, C24.1, C25.2, C26.2, C27.2, C28.2, C34.1, C35.1, C36.1, C55.2, D5.2 (A2), D7.1 (K), D8.1 (K), D9.1 (K), J4.2, R9.2, R14.2, R16.2, TP5.1 (1_1), U2.1 (GND), U2.9 (GND), U3.1 (GND), U3.9 (GND), U4.3 (GND), U5.2 (GND), U7.1 (GND), U7.4 (~ON), U7.5 (GND); also elsewhere on the board
unnamed: D5.1 (A1), F1.2, Q1.2 (D)
unnamed: D6.2 (A), Q1.1 (G), R9.1, R12.2
unnamed: D7.2 (A), R17.1
unnamed: D8.2 (A), R18.1
unnamed: D9.2 (A), R19.1
unnamed: F1.1, J4.1
unnamed: C13.1, U2.7 (BOOT)
unnamed: C16.2, R13.2, R14.1, U2.5 (FB)
unnamed: C14.1, U3.7 (BOOT)
unnamed: C17.2, R15.2, R16.1, U3.5 (FB)

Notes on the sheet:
Use buck to drop just above 5V so that ripple can be smoothed by 5V LDO
24V Input
24V to 5.17V Step-down Converter
FB R_{2} = (100k)/(V_{out} - 1)
24V to 12V Step-down Converter
+3.3V Regulation
USB ORing
+5V Regulation

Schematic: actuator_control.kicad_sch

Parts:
D11, D15, D19, D23: SK44BL; D_SMB; LCSC C151740
J7, J15, J22, J26: Conn_01x02; Molex_Micro-Fit_3.0_43650-0215_1x02_P3.00mm_Vertical; LCSC N/A
Q2, Q7, Q13, Q17: BSS138; SOT-23-3; LCSC C82045
R24, R36, R58, R66: 100; R_0603_1608Metric
R25, R33, R57, R65: 100k; R_0603_1608Metric; LCSC C122538

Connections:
+24V: D11.1 (K), D15.1 (K), D19.1 (K), D23.1 (K), J7.1, J15.1, J22.1, J26.1; also elsewhere on the board
ACT1_CTL: R24.1, R25.1; also elsewhere on the board
ACT2_CTL: R33.1, R36.1; also elsewhere on the board
ACT3_CTL: R57.1, R58.1; also elsewhere on the board
ACT4_CTL: R65.1, R66.1; also elsewhere on the board
GND: Q2.2 (S), Q7.2 (S), Q13.2 (S), Q17.2 (S), R25.2, R33.2, R57.2, R65.2; also elsewhere on the board
unnamed: D11.2 (A), J7.2, Q2.3 (D)
unnamed: D15.2 (A), J15.2, Q7.3 (D)
unnamed: D19.2 (A), J22.2, Q13.3 (D)
unnamed: D23.2 (A), J26.2, Q17.3 (D)
unnamed: Q2.1 (G), R24.2
unnamed: Q7.1 (G), R36.2
unnamed: Q13.1 (G), R58.2
unnamed: Q17.1 (G), R66.2


Board: 4 copper layers, 65.0 x 95.0 mm, 192 parts (0 on the bottom side), 104 nets.

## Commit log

2026-04-07 Placed the general sets of components.
    [ESP32-Breakout.kicad_sch, Power_Regulation.kicad_sch, QRET-ESP32.kicad_pcb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]
2026-04-07 General board shape, mounting holes, grounding plates.
    [ESP32-Breakout.kicad_sch, QRET-ESP32.kicad_pcb, QRET-ESP32.kicad_sch]
2026-04-07 Second draft of placement and wiring.
    [ESP32-Breakout.kicad_sch, Fan_Control.kicad_sch, QRET-ESP32.kicad_pcb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]
2026-04-07 Added labels and notes.
    [QRET-ESP32.kicad_pcb]
2026-06-03 update project to kicad v10
    [ADC1.kicad_sch, Actuator_Control.kicad_sch, Control_Heating.kicad_sch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]
2026-06-03 remove thermistors from board
    [ADCCircuitry.kicad_sch, QRET-ESP32.kicad_sch]
2026-06-03 rename project to be more descriptive
    [ADCCircuitry.kicad_sch, Actuator_Control.kicad_sch, ESP32-Breakout.kicad_sch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]
2026-06-03 fix load cell connector
    [ADCCircuitry.kicad_sch, Load_Cell.kicad_sch, gse_control_node.kicad_sch]
2026-06-03 switch to on-board esp32s3
    [ESP32-Breakout.kicad_sch, esp32s3_breakout.kicad_sch, gse_control_node.kicad_sch]
2026-06-03 fix fan header footprint
    [Fan_Control.kicad_sch, fan_control.kicad_sch, gse_control_node.kicad_sch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]
2026-06-03 update buck converter components and add reverse polarity protection
    [Actuator_Control.kicad_sch, Control_Heating.kicad_sch, actuator_control.kicad_sch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]
2026-06-03 do some pcb routing
    [actuator_control.kicad_sch, adc_filtering.kicad_sch, esp32s3_breakout.kicad_sch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]
2026-06-03 finish pcb routing
    [esp32s3_breakout.kicad_sch, gse_control_node.kicad_pcb, gse_control_node.kicad_sch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]
2026-06-03 remove unneccesary component fields
    [actuator_control.kicad_sch, adc_filtering.kicad_sch, esp32s3_breakout.kicad_sch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]
2026-06-03 add all lcsc part numbers
    [actuator_control.kicad_sch, adc_filtering.kicad_sch, esp32s3_breakout.kicad_sch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]
2026-06-03 add thermal reliefs on bottom power planes
    [gse_control_node.kicad_pcb]
2026-06-03 give more clearance for load cell connector from edge of board
    [gse_control_node.kicad_pcb]
2026-06-03 fix 5.17V buck switch node net name
    [gse_control_node.kicad_pcb, power_regulation.kicad_sch]
2026-06-03 switch to esp32-s3-wroom-1
    [esp32s3_breakout.kicad_sch, gse_control_node.kicad_pcb]
2026-06-03 update some routing and put ground pour on top layer to avoid warping
    [gse_control_node.kicad_pcb]
2026-06-03 update silkscreen
    [gse_control_node.kicad_pcb]
2026-06-03 update all capacitors to jlcpcb basic components
    [adc_filtering.kicad_sch, esp32s3_breakout.kicad_sch, gse_control_node.kicad_pcb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]
2026-06-03 add a 12v testpoint
    [actuator_control.kicad_sch, adc_filtering.kicad_sch, esp32s3_breakout.kicad_sch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]
2026-06-03 update resistors to jlcpcb basic components
    [actuator_control.kicad_sch, adc_filtering.kicad_sch, esp32s3_breakout.kicad_sch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]
2026-06-03 fix copper pour priorities
    [gse_control_node.kicad_pcb]
2026-06-03 move up ads112c04 capacitors further from pins for easier handsoldering
    [gse_control_node.kicad_pcb]
2026-06-03 remove some extended components from bom (to be handsoldered)
    [actuator_control.kicad_sch, esp32s3_breakout.kicad_sch, gse_control_node.kicad_pcb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]
2026-06-03 update screw terminal footprint
    [gse_control_node.kicad_pcb, gse_control_node.kicad_sch]
2026-06-03 add tachometer pullup and pwm low side fet for fans
    [actuator_control.kicad_sch, fan_control.kicad_sch, gse_control_node.kicad_pcb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]
2026-06-03 organize hierarchical sheet page numbers
    [gse_control_node.kicad_sch]
2026-06-04 update gitignore
    [gse_control_node.kicad_pcb]
2026-06-04 add back bss138 to jlcpcb bom
    [actuator_control.kicad_sch, fan_control.kicad_sch, gse_control_node.kicad_pcb]
2026-06-05 switch load cell connector to 5 pin with shield
    [gse_control_node.kicad_pcb, load_cell.kicad_sch]
2026-06-05 fix load cell silkscreen
    [gse_control_node.kicad_pcb, load_cell.kicad_sch]
2026-08-17 Heater/ignitor control (#2)
    * update project to kicad v10
    * remove thermistors from board
    * rename project to be more descriptive
    * fix load cell connector
    * switch to on-board esp32s3
    * fix fan header footprint
    * update buck converter components and add reverse polarity protection
    * do some pcb routing
    * finish pcb routing
    * remove unneccesary component fields
    * add all lcsc part numbers
    * add readme
    * add thermal reliefs on bottom power planes
    * give more clearance for load cell connector from edge of board
    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
    [actuator_control.kicad_sch, adc_filtering.kicad_sch, esp32s3_breakout.kicad_sch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]
